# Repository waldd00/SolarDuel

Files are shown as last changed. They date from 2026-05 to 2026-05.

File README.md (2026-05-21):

# ☀️ SolarDuel

### *A dual-axis solar tracker built as a controlled experiment, not a demo.*

<p align="center">
  
  
  
  
  
  
  
</p>

> SolarDuel runs a **motor-driven tracker** and a **fixed reference panel** side-by-side under identical irradiance, then quantifies the energy difference with a calibrated INA226 power monitor. The goal isn't just to track the sun — it's to **prove the gain**, with numbers.

---

## 📋 Table of Contents

- [What Makes This Different](#-what-makes-this-different)
- [System Architecture](#-system-architecture)
- [Bill of Materials](#-bill-of-materials)
- [Hardware Schematic](#-hardware-schematic)
- [System Photo](#-system-photo)
- [Control Pipeline — The Engineering Core](#️-control-pipeline--the-engineering-core)
- [Signal Flow Diagram](#-signal-flow-diagram)
- [Logger & Dashboard](#-logger--dashboard)
- [Efficiency Analysis Results](#-efficiency-analysis-results)
- [Repository Structure](#-repository-structure)
- [How to Run](#-how-to-run)
- [3D Print Settings](#️-3d-print-settings)
- [License](#-license)

---

## 🎯 What Makes This Different

Most LDR trackers on the internet are a four-resistor bridge wired into an `analogWrite()` loop. SolarDuel treats the same problem as a **real control engineering exercise**:

| Concern | Naïve tracker | SolarDuel |
|---|---|---|
| Sensor noise | Raw `analogRead()` | Per-channel **Kalman filter** + ADC oversampling |
| Hunting at boundary | Single threshold → chatter | **Adaptive deadband** with **2.5× hysteresis exit** |
| Twitching on light flicker | Acts on every blip | **Debounced activation** (confirmation counter) |
| Derivative kick on setpoint | None / unfiltered | **Derivative-on-measurement** with bilinear LPF |
| Integrator runaway at servo limit | Windup → overshoot | **Trapezoidal integration** + **conditional anti-windup** |
| Mechanical snap | Step PWM commands | **Slew-rate limiter** (15 μs / loop) |
| Boot-time shock | Servo snaps to home | **1-second soft-start ramp** |
| Loop timing jitter | `delay()` in `loop()` | **Fixed 200 Hz scheduler**, tick-overflow safe |
| Data acquisition vs. control | Same MCU → coupling | **Two isolated MCUs** — STM32 controls, ESP32 observes |

The result is a servo that moves like it has inertia — smoothly, decisively, and without the cricket-leg twitching that plagues hobby trackers.

---

## 🏗️ System Architecture

SolarDuel is deliberately split into two electrically and logically isolated units. The tracker never knows it's being measured; the logger never affects motor timing.

```
┌──────────────────────────────────────────────────────────┐
│                    TRACKER UNIT  (STM32)                 │
│                                                          │
│   4× LDR ──ADC──► STM32-G031K8 ──PWM──► 2× Servo (Pan/Tilt)
│                       │                                  │
│                       └─ Kalman → PID → Slew → Soft-LPF  │
└──────────────────────────────────────────────────────────┘

┌──────────────────────────────────────────────────────────┐
│                    LOGGER UNIT  (ESP32)                  │
│                                                          │
│   Panel ──► 47 Ω load ──► INA226 ──I²C──► ESP-WROOM-32   │
│                                              │           │
│                                              ├─► WiFi → Browser dashboard
│                                              └─► /csv  → Timestamped CSV
└──────────────────────────────────────────────────────────┘
```

---

## 🧰 Bill of Materials

| Component | Role / Specification | Qty |
|---|---|---:|
| **STM32-NUCLEO-G031K8** | Tracker MCU — LDR sampling, control loop, PWM | 1 |
| **ESP-WROOM-32** | Logger MCU — INA226 readout, web server, CSV export | 1 |
| **LDR (GL5528 class)** | Cross-placed light sensors, 3.3 V dividers | 4 |
| **INA226** | 16-bit I²C power monitor, 0.1 Ω shunt | 1 |
| **Servo (MG996R / SG90)** | Pan + tilt actuators | 2 |
| **Solar panel** | 6 V / 150 mA monocrystalline | 2 |
| **Dummy load** | 47 Ω 5 W ceramic resistor (MPP-adjacent operating point) | 1 |
| **Resistors** | 10 kΩ LDR voltage dividers | 4 |
| **Power supply** | 5 V / 3 A external adapter (servos) | 1 |
| **Mechanical** | Custom 3D-printed pan-tilt frame, PLA | — |

---

## 🔌 Hardware Schematic

Full wiring for both units — tracker (STM32 + LDRs + servos) and logger (ESP32 + INA226 + dummy load):

📄 **[Hardware Schematic (PDF)](Hardware/hardware_schematic.pdf)**

**Wiring highlights:**
- INA226: `SDA → GPIO21`, `SCL → GPIO22` on the ESP32
- LDRs: 10 kΩ dividers to 3.3 V, outputs to STM32 ADC channels 0, 1, 4, 5
- Servos powered from the **external 5 V adapter** — never from the STM32 3.3 V rail
- 47 Ω dummy load sits across the panel terminals to pull operation toward the MPP

---

## 📷 System Photo

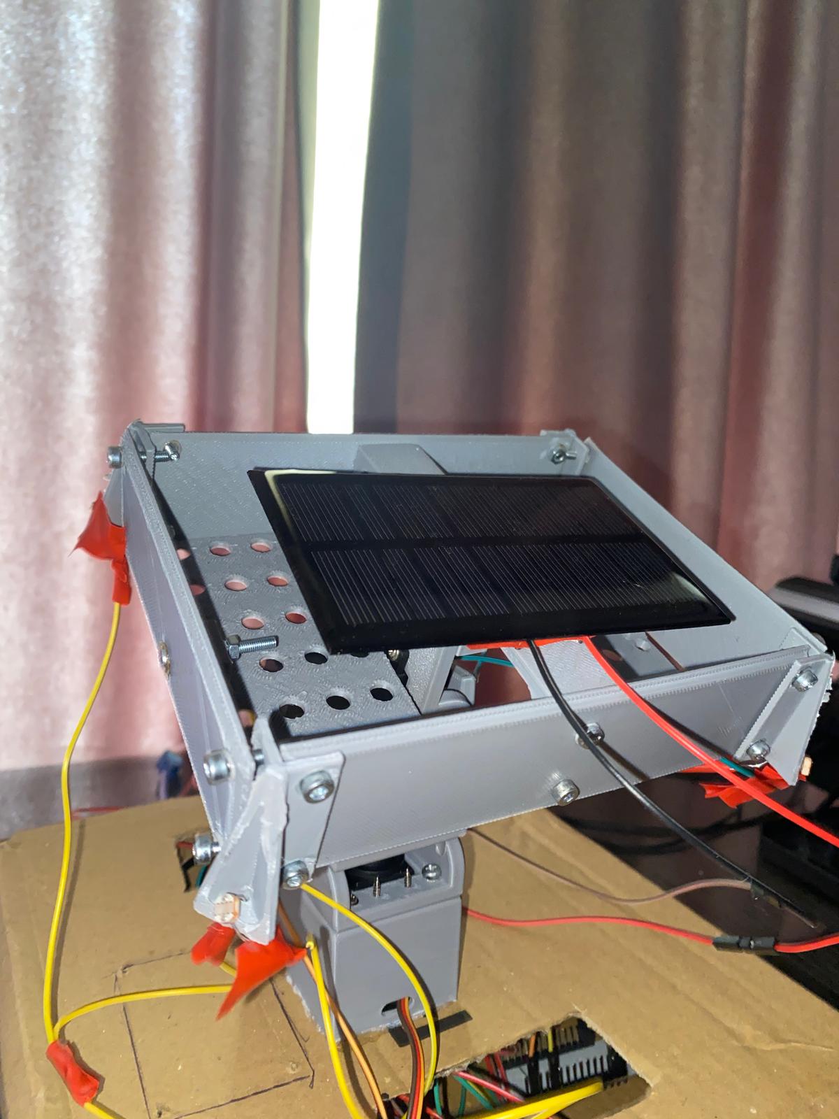
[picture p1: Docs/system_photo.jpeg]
System Photo


---

## ⚙️ Control Pipeline — The Engineering Core

The control stack is built as a chain of independent stages. Each stage solves one specific real-world failure mode of a basic LDR tracker.

### Stage 1 — ADC Oversampling
Each LDR is sampled **3 times in software** per loop and averaged. Cheap, immediate noise reduction before any filtering.

### Stage 2 — Per-Channel Kalman Filter
A 1-D Kalman filter runs on each of the four LDR streams independently:
```
k.p = k.p + q
kg  = k.p / (k.p + r)
k.x = k.x + kg · (z − k.x)
k.p = (1 − kg) · k.p
```
Tuned with `q = 2.0, r = 200.0` — biased toward smoothness because real solar light changes slowly relative to sensor noise.

### Stage 3 — Adaptive Deadband
A fixed deadband fails: too tight under bright sun (chatter), too loose at dawn (poor pointing). SolarDuel scales the deadband with **measured ambient light**:
```
tol = TOL_MIN + (ambient / 4096) × (TOL_MAX − TOL_MIN)   →   tol ∈ [50, 80] ADC units
```
Brighter ambient → larger differential noise → wider deadband. The controller stays still when it should.

### Stage 4 — Debounced Activation
A single noisy sample shouldn't wake the motor. The controller requires **`CONFIRM_THRESH = 2` consecutive out-of-band samples** before activating. Transient cloud edges no longer trigger pointless servo movements.

### Stage 5 — PID with Industrial-Grade Features

Not a textbook PID. Four upgrades over the naïve form:

**a) Trapezoidal (Tustin) integration**
```c
integral += 0.5 · (error + prev_error) · dt
```
More accurate than rectangular integration at the loop's ~200 Hz rate.

**b) Derivative on measurement**
Differentiating *error* causes a "derivative kick" on any setpoint change. SolarDuel differentiates the **measurement** instead — same dynamic response, no kick.

**c) Bilinear-LPF on derivative**
Raw `dD/dt` is a noise amplifier. The D-term passes through a first-order discrete LPF:
```
c1 = (1 − k) / (1 + k),   c2 = k / (1 + k),   k = α/2
d_filtered = c1 · d_filtered + c2 · (raw_d + prev_raw_d)
```
Removes the high-frequency chatter that makes textbook PID unusable on servos.

**d) Hysteresis exit + asymmetric thresholds**
Once active, the controller doesn't deactivate at the same threshold it entered:
```
thr_enter = tol         → wake the motor
thr_exit  = tol × 2.5   → only sleep when well back inside
```
This kills limit-cycling at the boundary — a problem most hobby trackers never solve.

### Stage 6 — Slew Rate Limiter
PID output is clamped to **±15 μs per loop** before being added to the servo target. Mechanically jarring fast moves are physically impossible.
```c
if (Δ >  MAX_DELTA_PER_LOOP) Δ =  MAX_DELTA_PER_LOOP;
if (Δ < -MAX_DELTA_PER_LOOP) Δ = -MAX_DELTA_PER_LOOP;
```

### Stage 7 — Conditional Anti-Windup at Saturation
When the target hits the mechanical limit (`PAN_MAX`, `TILT_MIN`, etc.), the integrator is checked: any component pushing **further into** the limit is zeroed, but useful "pull-back" integral is preserved. Cleaner than blanket clamping.

### Stage 8 — Float-Rounded PWM Write
A subtle but real artifact: casting `float → uint16_t` **truncates**, creating 1-step quantization jitter. All PWM writes use:
```c
__HAL_TIM_SET_COMPARE(&htim1, ch, (uint16_t)(pos + 0.5f));
```
The `+ 0.5f` converts truncation into proper rounding. Last source of micro-stepping eliminated.

### Stage 9 — Soft-Start
On boot, servos ramp from `PAN_MIN`/`TILT_MIN` to home over **50 steps × 20 ms = 1 second**, instead of snapping. Prevents power-up inrush and mechanical shock.

### Stage 10 — Fixed-Period, Overflow-Safe Scheduler
Loop runs at exactly **200 Hz** (`LOOP_PERIOD_MS = 5`) using non-blocking `HAL_GetTick()` comparison with **signed-cast tick-rollover handling** (49-day wrap is correctly handled). If execution falls more than 100 ms behind (e.g., debugger pause), the scheduler resyncs instead of catch-up-bursting.

---

## 📡 Signal Flow Diagram

```
4× LDR
   │
   ▼  ADC oversampling (3 samples / channel)
Kalman filter (per channel, q=2.0, r=200.0)
   │
   ▼  computed each loop
Edge averages  →  ambient light  →  adaptive deadband
   │
   ▼
Differential error    (right−left)   and   (bottom−top)
   │
   ▼
Debounce confirm counter   (CONFIRM_THRESH = 2)
   │
   ▼
PID — Tustin integration + filtered D-on-measurement
   │
   ▼  ±MAX_DELTA_PER_LOOP
Slew rate limiter
   │
   ▼
Target update  →  conditional anti-windup at limits
   │
   ▼  (+ 0.5f) cast
Float-rounded PWM compare register write
   │
   ▼
Servo
```

---

## 🌐 Logger & Dashboard

The ESP32 logger runs an independent **HTTP server + live JSON API** on the local network. No cloud, no app, no broker — open the IP in any browser.

**Features:**
- 🟢 1 Hz refresh of voltage, current, power, energy, efficiency
- 📈 Live **60-second rolling power graph** rendered on canvas
- ⏺ One-click **CSV recording** (`Time, V, mA, mW, Wh`) with timestamped filename
- 🔄 **Reset** clears energy accumulator and graph buffer
- 📊 Up to **3600 entries** (1-hour session at 1 Hz) buffered in RAM
- ⚡ Efficiency is computed against the panel's rated `PANEL_MAX_W = 0.9 W`

The dashboard is served as a single in-flash `PROGMEM` HTML page with vanilla JS — no external libraries, no build step.

---

## 📊 Efficiency Analysis Results

A 3-hour A/B session (10:00–13:00) under natural sunlight, panels swapped under matched irradiance, data processed in MATLAB.

| Metric | Tracker | Fixed Panel |
|---|---:|---:|
| Peak Efficiency | **74.44 %** | 35.00 % |
| Average Efficiency | **52.31 %** | 21.14 % |
| Peak Power | **670.0 mW** | 315.0 mW |
| Average Power | **470.8 mW** | 190.2 mW |
| Total Energy Harvested | **1.4125 Wh** | 0.5707 Wh |
| Tracker Energy Gain | — | **+147.5 %** |
| Avg. Instantaneous Gain | — | **180.3 %** |

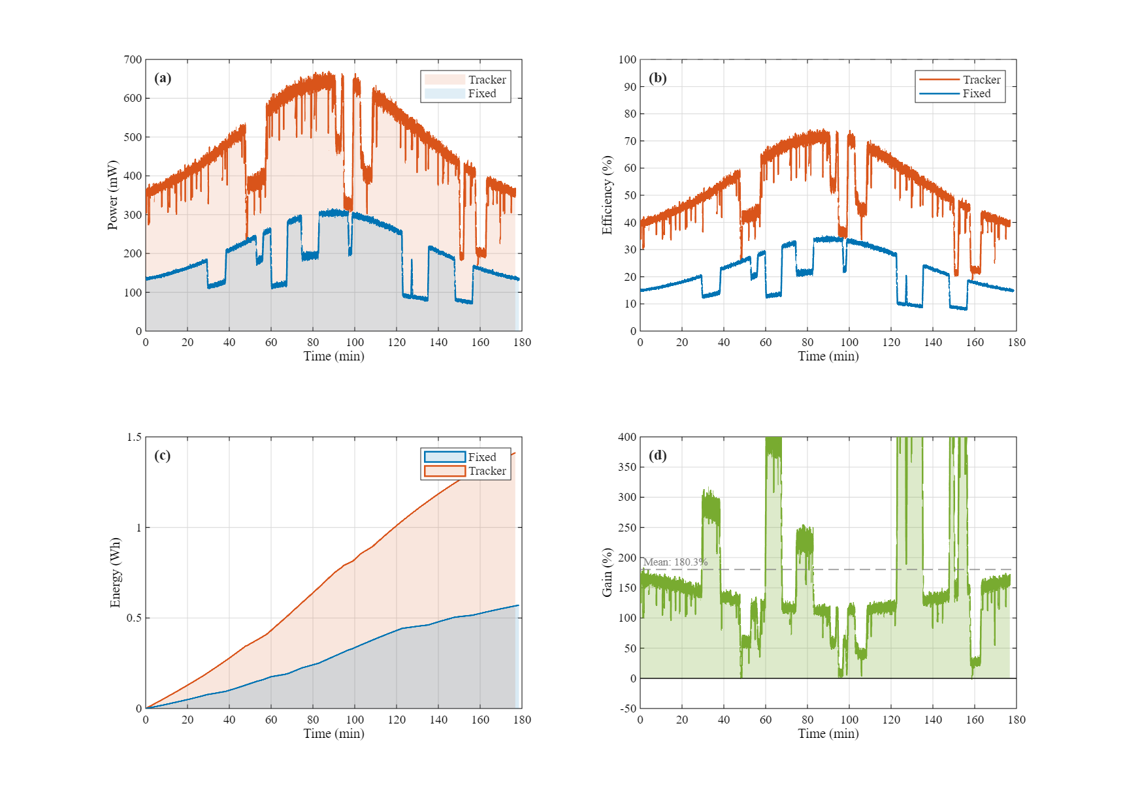
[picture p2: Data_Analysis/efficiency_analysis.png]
Efficiency Analysis


> **(a)** Instantaneous power output. The tracker consistently delivers more power, with both panels showing characteristic cloud-induced dips. **(b)** Panel efficiency relative to the 0.9 W rated maximum. **(c)** Cumulative energy harvested. **(d)** Instantaneous tracker gain over fixed — averaging **~180 %** highlights the value of continuous sun-facing orientation.

---

## 📂 Repository Structure

```
SolarDuel/
├── CAD_Files/STL/                  # Print-ready STL files for pan-tilt structure
├── Hardware/
│   └── hardware_schematic.pdf      # Full wiring schematic
├── Docs/
│   ├── dashboard.png               # Web dashboard preview
│   └── system_photo.jpeg           # Physical system photo
├── Software_STM32_Control/         # STM32CubeIDE project — tracker firmware (C, HAL)
├── Software_ESP32_Logger/          # Arduino IDE project — INA226 + web dashboard
└── Data_Analysis/
    ├── tracker_panel_data.csv      # Logged data — tracking panel
    ├── fixed_panel_data.csv        # Logged data — fixed panel
    ├── efficiency_analysis.m       # MATLAB analysis script
    └── efficiency_analysis.png     # Output figure
```

---

## 🧑‍💻 How to Run

**1 — Tracker (STM32)**
- Open `Software_STM32_Control` in STM32CubeIDE.
- Compile and flash to the NUCLEO-G031K8.
- Power LDRs from 3.3 V, servos from the external 5 V adapter.
- On boot, the soft-start routine ramps the servos to home over ~1 s.

**2 — Logger (ESP32)**
- Open `Software_ESP32_Logger` in Arduino IDE.
- Install the `INA226_WE` library from Library Manager.
- Set your WiFi credentials at the top of the sketch.
- Flash to the ESP32; wire `SDA → GPIO21`, `SCL → GPIO22`.
- Connect the active panel to the INA226 input, with the 47 Ω dummy load to ground.
- Open Serial Monitor (115200 baud) — the assigned IP is printed on boot.
- Browse to `http://<IP>` from any device on the same network.

**3 — Data Collection**
- Click **⏺ Start Recording** on the dashboard.
- Click **⏹ Stop & Download CSV** when done — file is saved with an ISO timestamp.
- Swap panels under matched conditions and repeat for the A/B pair.

**4 — Analysis**
- Place both CSVs and `efficiency_analysis.m` in the same folder.
- Run the script in MATLAB — summary table prints to console, figure saves as `efficiency_analysis.png`.

---

## 🖨️ 3D Print Settings

| Parameter | Value |
|---|---|
| Printer | Creality CR-10 Smart Pro |
| Slicer | Creality Slicer |
| Material | PLA |
| Infill | 15 % |
| Supports | Per-part — check STL orientation |

> **Attribution:** STL files in `CAD_Files/STL/` are sourced from [this Instructables project](https://www.instructables.com/SOLAR-TRACKER-TILTPAN-PANEL-FRAME-LDR-MOUNTS-RIG/) and are not original work. All credit goes to the original author. Files are shared here under the terms of the original license for non-commercial, educational use only.

---

## 📄 License

This project is licensed under the **MIT License** — see the [LICENSE](LICENSE) file for details.

---

<p align="center">
  <em>SolarDuel is an applied engineering study at the intersection of</em><br>
  <strong>automatic control theory · embedded systems · data-driven performance analysis.</strong>
</p>

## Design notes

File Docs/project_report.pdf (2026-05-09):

Contents

Contents

1 Abstract | 1
2 Introduction | 1
3 System Architecture | 2
4 Hardware and Circuit Design | 3
5 Sensors | 5
6 Actuators | 6
7 Control Strategy | 6
8 Software Architecture | 9
9 Data Collection and A/B Test Method | 9
10 Efficiency Analysis | 10
11 Conclusions | 13
Bibliography | 14
A STM32 Control Loop — Core Flow | 14

i

Chapter 2. Introduction

### 1. Abstract

This study presents the design and implementation of a dual-axis solar tracking system that determines the solar azimuth and elevation angle using differential signals from four LDR sensors. The system consists of two independent units: an STM32G031K8 microcontroller for motor control and an ESP32 microcontroller for power measurement and data logging. Power monitoring is performed via an INA226 module over the I2C protocol.

The control architecture employs a multi-layer signal processing pipeline consisting of a Kalman filter, moving average, a full PID controller with anti-windup and derivative filter, hysteresis dead band, and exponential position smoothing. Power data acquired across a 47 Ω dummy load is monitored in real time through a live web dashboard running on the ESP32 and recorded in CSV format.

Comparative A/B testing between the tracking and fixed panel configurations shows that the tracker produces %147.5 more gross energy over a three-hour measurement session. A parasitic consumption analysis reveals that the MG996R servo motors present a disproportionate load relative to the panel capacity, highlighting the critical role of actuator selection in small-scale tracking systems.

### 2. Introduction

Panel efficiency in solar energy systems is directly related to the angular orientation of the panel relative to incident irradiance. A fixed-mount photovoltaic panel can only achieve its optimum angle for a limited period each day due to the apparent motion of the sun. Solar tracking systems aim to minimise this loss by continuously orienting the panel perpendicular to the incoming radiation [1].

While single-axis trackers follow only the azimuth angle, dual-axis systems control both azimuth and elevation simultaneously to achieve higher energy yield [2]. This work presents a system in which a solar panel mounted on a two-servo pan-tilt mechanism is directed by differential signals derived from four LDR sensors.

The primary objectives of the project are:

- Sun angle estimation using four cross-placed LDR sensors
- Jitter-free, precise servo control through a multi-layer control architecture
- High-accuracy power and energy measurement with the INA226
- A live ESP32-based web dashboard with browser-side CSV recording
- Quantitative efficiency comparison against a fixed panel

Chapter 3. System Architecture

### 3. System Architecture

The system is intentionally split into two isolated units to ensure that data acquisition is never affected by motor control timing or interrupt latency.

Tracker Unit (STM32): Processes LDR signals and drives the servo motors via PWM. All control algorithms run on this unit.

Logger Unit (ESP32): Reads panel power data from the INA226, serves a live web dashboard, and handles CSV recording. It has no direct connection to the motor control unit.


Figure 3.1: Assembled dual-axis solar tracking system

Chapter 4. Hardware and Circuit Design

### 4. Hardware and Circuit Design

### 4.1 Bill of Materials

Table 4.1: Project bill of materials

Component | Role / Specification | Qty
STM32-NUCLEO-G031K8 Primary MCU — motor and LDR control | 1
ESP-WROOM-32 | Secondary MCU — logging and web server | 1
LDR | Light sensor, 10 kΩ voltage divider | 4
INA226 | Bi-directional power monitor (I2C, 0.1 Ω shunt) 1
Dummy Load | 47 Ω 5W ceramic resistor | 1
Servo Motor | Pan and tilt axis actuators | 2
Solar Panel | 6 V 150 mA monocrystalline | 2
Resistor | 10 kΩ LDR voltage dividers | 4
Power Supply | 5 V 3 A external adapter | 1
Mechanical | Custom 3D-printed PLA pan-tilt structure [3] | —

### 4.2 Circuit Design

A critical design decision is powering the servo motors from an external 5 V adapter rather than the STM32’s 3.3 V rail. The inrush current drawn by the servos would otherwise cause voltage drops on the MCU power rail, corrupting ADC readings. The 47 Ω dummy load was selected to force the 6 V/150 mA panel to operate near its maximum power point.

Chapter 4. Hardware and Circuit Design

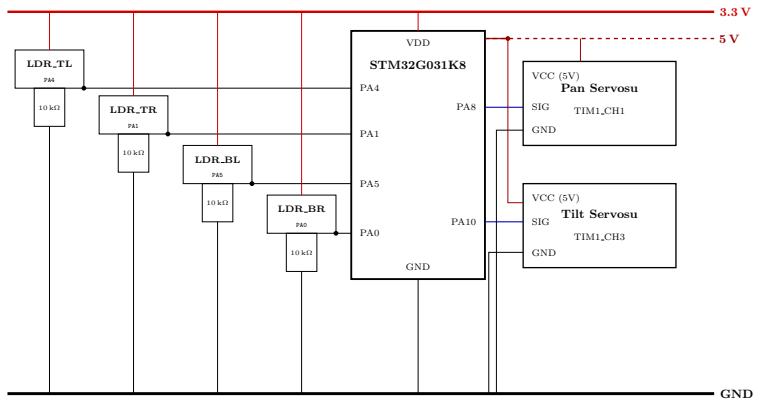
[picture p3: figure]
GND; LDR TL; LDR TR; LDR BL; LDR BR; STM32G031K8; VDD; Pan Servosu; TIM1 CH1; VCC (5V); SIG; Tilt Servosu; TIM1 CH3

Figure 4.1: System circuit schematic (1/2)

### 3.3 V

GND

G¨une¸s

Paneli

6V / 150mA

Monokristal

+

−

INA226

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
### 47 Ω

5W

ESP32-WROOM-32

GPIO21 (SDA)

GPIO22 (SCL)

3.3V

GND

3V3

GND

SDA

SCL

Figure 4.2: System circuit schematic (2/2)

Chapter 5. Sensors

### 5. Sensors

### 5.1 LDR (Light-Dependent Resistor)

An LDR is a photoconductive element whose resistance decreases proportionally with incident light intensity — from several MΩ in darkness to a few hundred Ω under full illumination.

Four LDRs are placed at the corners of the panel frame in a cross configuration: top-left, top-right, bottom-left, and bottom-right. Each sensor forms a voltage divider with a 10 kΩ fixed resistor, with the output fed to an STM32 ADC input. The differential signal method is defined as:

epan = ADClef t − ADCright | (5.1)
etilt = ADCtop − ADCbottom | (5.2)

When epan > 0 the panel rotates left; when etilt > 0 it tilts upward. Both errors approaching zero indicates the panel is perpendicular to the sun.

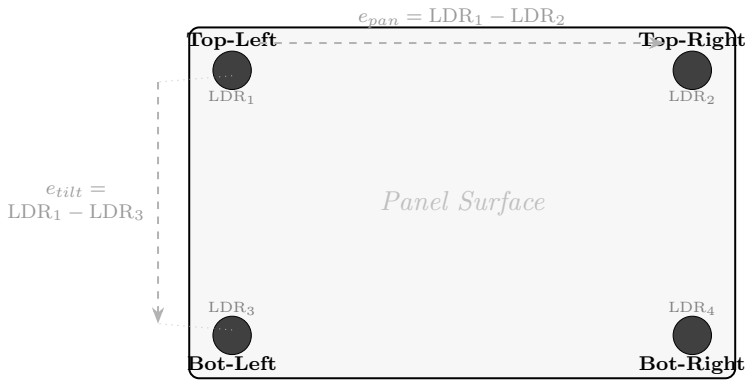
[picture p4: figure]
Panel Surface; Top-Left; LDR1; Top-Right; LDR2; Bot-Left; LDR3; Bot-Right; LDR4; epan = LDR1 − LDR2; etilt = LDR1 − LDR3

Figure 5.1: Cross-placement of LDR sensors at panel corners with differential signal definitions

### 5.2 INA226 Power Monitor

The INA226 is an I2C power monitor that measures the voltage drop across a shunt resistor to compute current, bus voltage, and power with high accuracy [4]. A 0.1 Ω shunt resistor is used with a maximum measurement range of 1.5 A.

Listing 5.1: INA226 initialisation and calibration

1 | ina226 . setResistorRange (0.1 , 1.5) ; | // 0.1 Ohm shunt , max 1.5
| A
2 | ina226 . setAverage ( INA226_AVERAGE_16 ) ; | // 16 - sample hardware
| averaging

Chapter 7. Control Strategy

Hardware averaging over 16 samples suppresses high-frequency noise at the sensor level. Cumulative energy is computed via discrete integration:

EW h =

## XPW ·

∆t
3600

(5.3)

### 6. Actuators

### 6.1 Servo Motors

Servo motors are angle-positioning actuators controlled by the duty cycle of a PWM signal. Typically, a 1 ms pulse corresponds to 0° and a 2 ms pulse to 180°.

Two servo motors are used — one for the pan (azimuth) axis and one for the tilt (elevation) axis — driven by STM32 Timer1 PWM outputs independently. Since the position value is stored as a float, a rounding correction is applied at the PWM write step to prevent quantisation jitter:

Listing 6.1: Float-preserving PWM write

1 | __HAL_TIM_SET_COMPARE (& htim1 , TIM_CHANNEL_1 ,
2 | ( uint16_t ) ( pos_pan + 0.5 f ) ) ;

The +0.5f offset converts truncation to proper rounding, eliminating the last source of micro-stepping artifacts. A soft-start routine ramps the servos to the home position over 1 second on power-up.

### 7. Control Strategy

The system employs a six-layer signal processing pipeline in which each layer addresses a specific real-world problem. The full pipeline is illustrated in Figure 7.1 and all tunable parameters are summarised in Table 7.1.

Chapter 7. Control Strategy

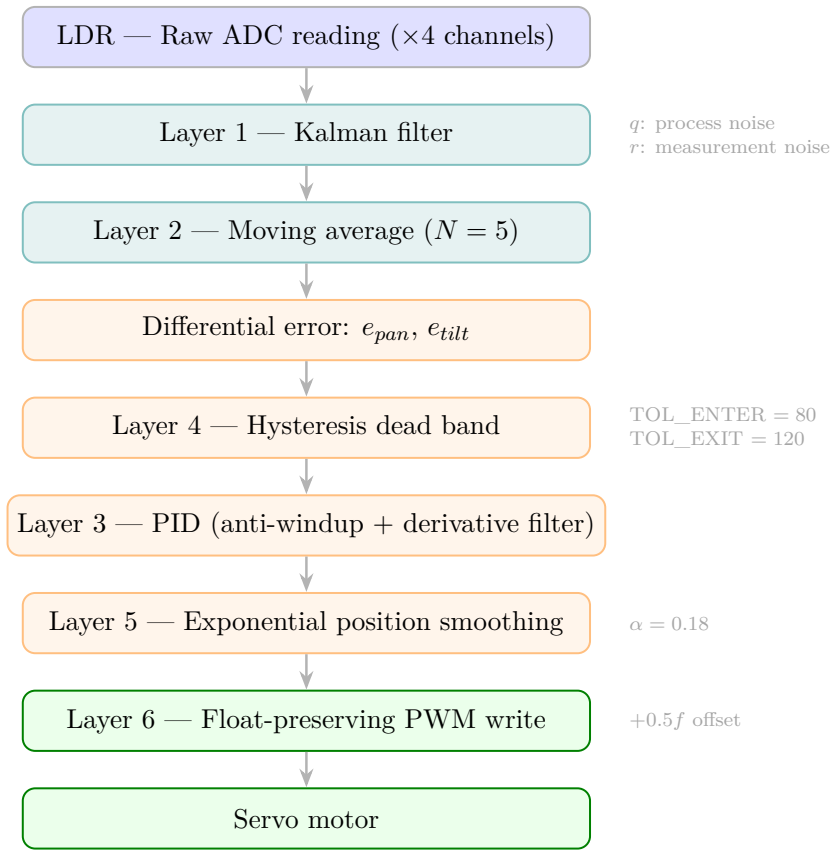
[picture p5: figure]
LDR — Raw ADC reading (×4 channels); Layer 1 — Kalman filter; Layer 2 — Moving average (N = 5); Differential error: epan, etilt; Layer 4 — Hysteresis dead band; Layer 6 — Float-preserving PWM write; Servo motor; q: process noise r: measurement noise; TOL_ENTER = 80 TOL_EXIT = 120; +0.5f offset

Layer 3 — PID (anti-windup + derivative filter)

Layer 5 — Exponential position smoothing

Sensor | Filtering | Control | Output

Figure 7.1: Control system signal processing pipeline

Table 7.1: Control and system parameter summary

Layer / Component | Parameter | Value
Kalman filter | Process noise q | Tunable
| Measurement noise r | Tunable
Moving average | Window size N | 5
Hysteresis dead band | Activation threshold TOL_ENTER | 80
| Deactivation threshold TOL_EXIT | 120
Exponential smoothing Smoothing factor α | 0.18
PWM write | Rounding offset | +0.5f
INA226 | Shunt resistance | 0.1 Ω
| Maximum current | 1.5 A
| Hardware averaging | 16 samples
Solar panel | Rated voltage | 6 V
| Rated current | 150 mA
| Maximum power | 0.9W
Dummy load | Resistance | 47 Ω
Servo (MG996R) | Idle consumption (×2) | 1700 mW
| Active duty cycle | 2.5%

Chapter 7. Control Strategy

### 7.1 Layer 1 — Kalman Filter

Raw ADC readings contain significant high-frequency noise, particularly under partially cloudy conditions. A 1D Kalman filter runs independently on each of the four LDR channels, separating genuine light-level changes from sensor noise [5].

xˆk|k = ˆxk|k−1 + Kk(zk − xˆk|k−1) | (7.1)

Increasing the measurement noise parameter r produces a smoother but slower response.

### 7.2 Layer 2 — Moving Average (N = 5)

A 5-sample circular moving average is applied on top of the Kalman output. This dual-stage filtering virtually eliminates transient spikes caused by cloud edges or mechanical vibration.

### 7.3 Layer 3 — PID Controller

The differential error feeds into a full PID controller with two key enhancements:

Anti-windup (integral clamping): When the servo is at its mechanical limit, the integrator is hard-clamped to ±ilimit to prevent windup and overshoot on release.

Filtered derivative: A first-order low-pass filter is applied to the raw derivative term before it reaches the output:

df iltered = α · draw + (1 − α) · df iltered,prev | (7.2)

### 7.4 Layer 4 — Hysteresis Dead Band

A two-threshold hysteresis band prevents the chattering that occurs when using a single threshold:

- TOL_ENTER = 80: Motor activates when error exceeds this value
- TOL_EXIT = 120: Motor deactivates only when error drops below this value

### 7.5 Layer 5 — Exponential Position Smoothing

The target servo position is passed through a first-order exponential smoother to produce an organic, inertia-like motion profile:

pos = pos + α · (target − pos), | α = 0.18 | (7.3)

### 7.6 Layer 6 — Float-Preserving PWM Write

Direct float → uint16_t casting truncates rather than rounds, creating invisible one-step quantisation jitter. The +0.5f offset corrects this.

Chapter 9. Data Collection and A/B Test Method

### 8. Software Architecture

### 8.1 STM32 Firmware

The STM32 firmware is written in C using the HAL library. The main loop executes ADC reading, Kalman + moving average filtering, PID computation, and PWM write in sequence.

### 8.2 ESP32 Web Server

The ESP32 exposes the following HTTP endpoints via the AsyncWebServer library:

Table 8.1: ESP32 HTTP endpoints

Endpoint Function

/ | Live web dashboard (HTML)
/data | Real-time measurement data (JSON)
/start | Begin CSV recording session
/stop | Stop recording and prepare download
/csv | Download recorded data as CSV
/reset | Clear all runtime data

The last 3600 measurements (1 hour) are held in a circular buffer in RAM and served via chunked transfer, avoiding large heap allocations.

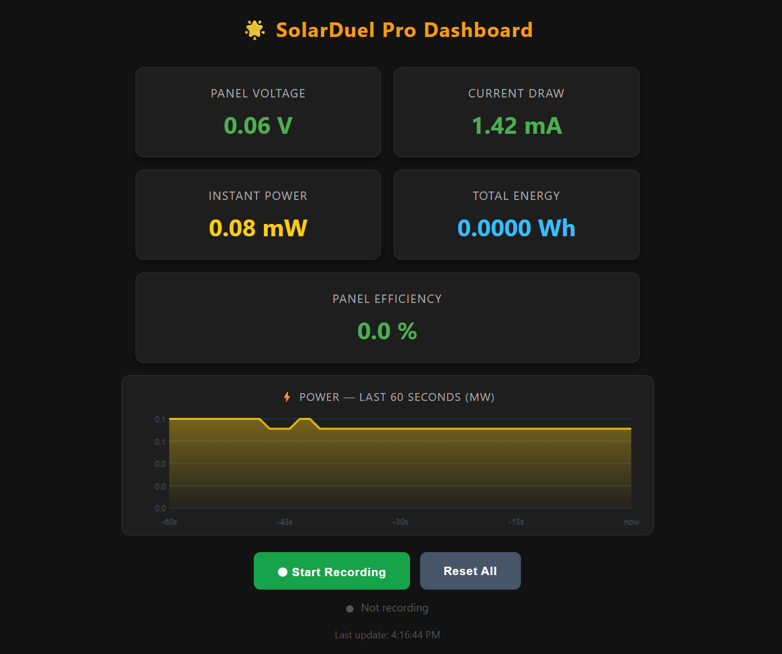
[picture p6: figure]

Figure 8.1: ESP32 live web dashboard

### 9. Data Collection and A/B Test Method

Since both panels cannot be connected to the INA226 simultaneously, an A/B test methodology was used. Under matched irradiance conditions, the tracker panel and the

Chapter 10. Efficiency Analysis

fixed panel were each connected to the same dummy load in separate sessions. Recording was initiated via the Start Recording button on the dashboard and the resulting CSV was downloaded with Stop & Download CSV.

Each dataset contains time (s), voltage (V), current (mA), power (mW), and cumulative energy (Wh). The dataset used for analysis consists of 10 800 rows (3-hour session, 1 sample per second).

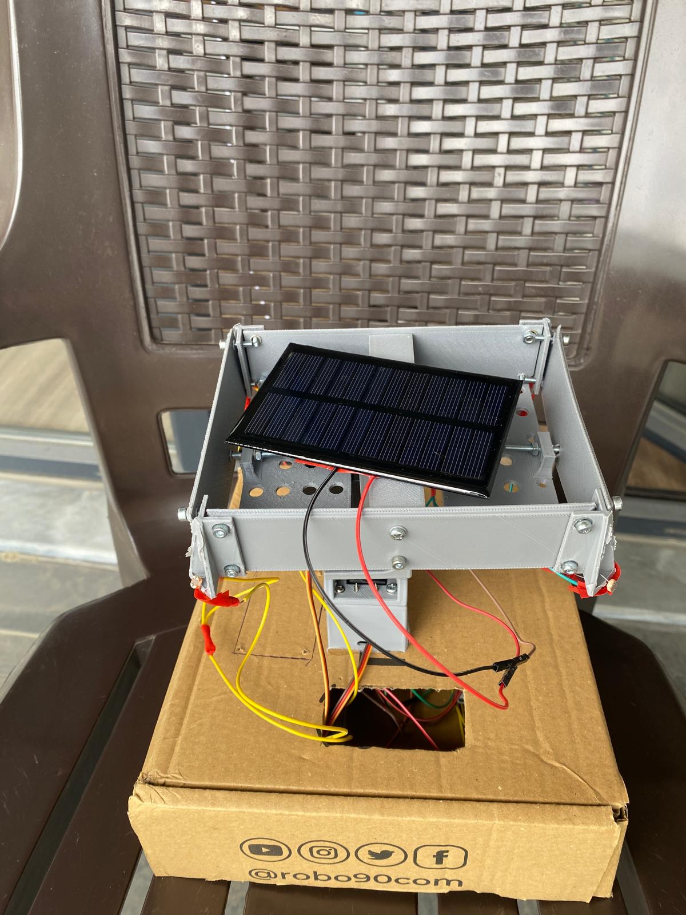
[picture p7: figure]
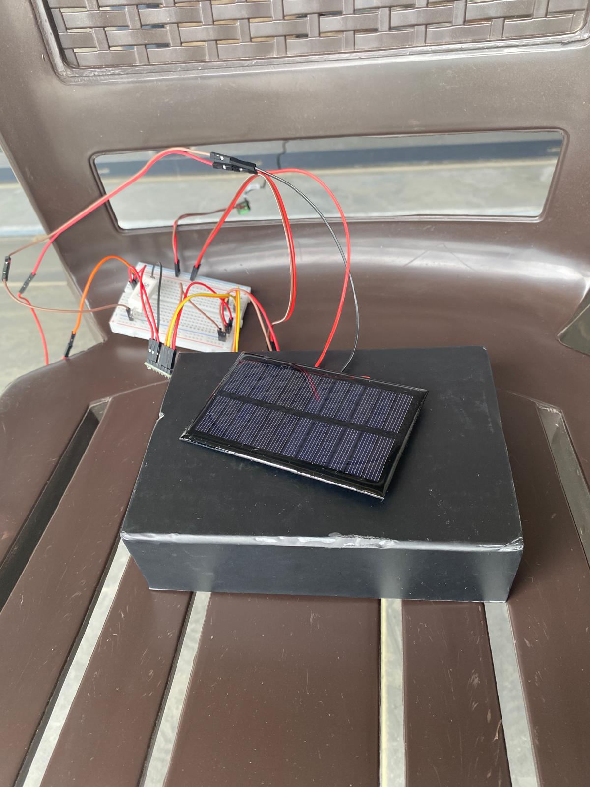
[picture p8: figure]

(a) Tracker panel session | (b) Fixed panel session

Figure 9.1: A/B test setup: each panel connected separately to the same load for matched measurements

### 10. Efficiency Analysis

The MATLAB analysis script (efficiency_analysis.m) processes both CSV files and produces a four-panel comparative figure.

Chapter 10. Efficiency Analysis

### 10.1 Results Summary

Table 10.1: Tracker vs fixed panel comparative efficiency results

Metric | Tracker Fixed Panel
Peak Efficiency | 74.44% | 35.00%
Average Efficiency | 52.31% | 21.14%
Peak Power | 670.0 mW | 315.0 mW
Average Power | 470.8 mW | 190.2 mW
Total Energy Harvested | 1.4125Wh | 0.5707Wh
Energy Gain | +147.5% | —
Avg. Instantaneous Gain | 180.3% | —

### 10.2 Analysis Figures

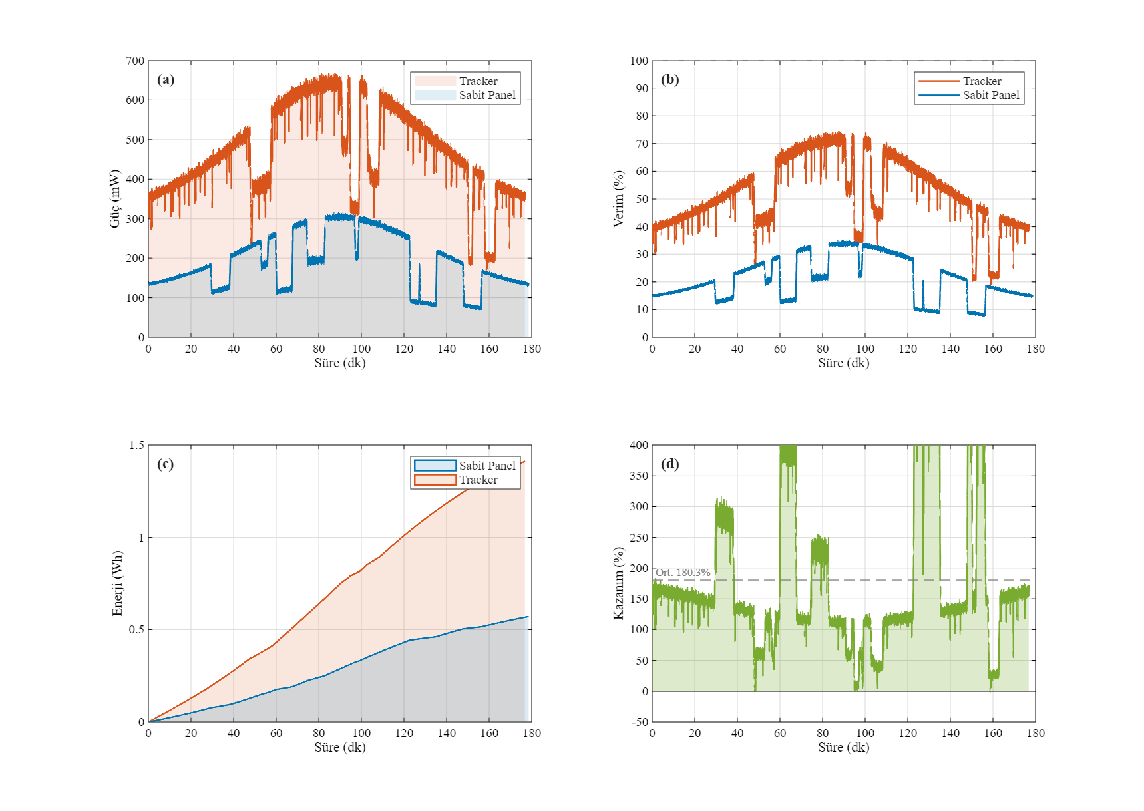
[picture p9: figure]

Figure 10.1: Comparative efficiency analysis: (a) instantaneous power, (b) panel efficiency,
(c) cumulative energy, (d) tracker gain over fixed

Figure 10.1(a) shows that the tracker consistently delivers higher power throughout the session, with characteristic cloud-induced dips visible in both curves. Figure 10.1(c) shows the tracker harvesting 1.41Wh versus 0.57Wh for the fixed panel over the same period. The average instantaneous gain of 180.3% shown in Figure 10.1(d) confirms the advantage of continuous sun-facing orientation.

Chapter 10. Efficiency Analysis

### 10.3 Net Energy Gain and Parasitic Consumption Analysis

For the gross energy advantage to be meaningful from an engineering standpoint, the parasitic energy consumed by the tracking system itself must be accounted for. This analysis is critical for evaluating the true efficiency of solar tracking systems, as emphasised by Seme et al. [2].

### 10.3.1 Parasitic Consumption Estimate

Table 10.2: Tracker unit component power consumption

Component | Idle (mW) Active (mW) | Source
STM32G031K8 | 15 | 15 | Datasheet
Servo Motor ×2 (MG996R) | 1700 | 5000 MG996R Datasheet
Total | 1715 | 5015

The servos are not continuously active; they engage only when the LDR differential error exceeds the hysteresis threshold (TOL_ENTER = 80). Given that the sun moves approximately 15° per hour, the servo active duty cycle is estimated at approximately 2.5% (roughly 3 seconds of motion every 2 minutes).

### 10.3.2 Net Energy Calculation

Parasitic energy over the 3-hour session:

ESTM32 = 15 mW × 3 h = 45 mWh | (10.1)
Eservo,idle = 1700 mW × (1 − 0.025) × 3 h = 4972 mWh | (10.2)
Eservo,active = 5000 mW × 0.025 × 3 h = 375 mWh | (10.3)
Eparasitic = 45 + 4972 + 375 = 5392 mWh ≈ 5.392Wh | (10.4)

Table 10.3: Net energy gain analysis (3-hour session)

Parameter | Value (Wh) | Note
Tracker gross energy | 1.4125 | INA226 measurement
Fixed panel energy | 0.5707 | INA226 measurement
Gross energy gain | +0.8418 | Tracker − Fixed
Parasitic consumption | −5.3920 STM32 + 2× MG996R
Net energy gain | −4.550 | Gross − Parasitic

The net energy analysis reveals that the MG996R servos present a disproportionate parasitic load for a 6 V/150 mA panel: each servo draws approximately 850 mW at idle, close to the panel’s entire rated output of 900 mW. This finding underscores the critical

Chapter 11. Conclusions

importance of actuator selection in small-scale tracking systems. A redesign using lower-power micro-servos (e.g., SG90: ∼50 mW/servo idle) or higher-capacity panels is expected to yield a positive net energy gain.

### 11. Conclusions

The dual-axis solar tracking system presented in this work produces 147.5% more gross energy than the fixed panel configuration over a three-hour measurement session. The net energy analysis shows that the MG996R servo motors consume more power at idle than the panel produces, highlighting that actuator selection is the dominant factor in the energy balance of small-scale tracking systems.

The multi-layer control architecture effectively suppresses high-frequency LDR noise and servo chattering. The physical separation of the STM32 tracker unit and the ESP32 logger unit ensures that data acquisition is not affected by motor control latency.

Strengths of the system include the real-time web dashboard, browser-side CSV recording, and hardware-level measurement averaging (INA226 16-sample average). Limitations include the sequential A/B test methodology, which cannot capture both panels simultaneously, and the 3-hour measurement window.

Appendix A. STM32 Control Loop — Core Flow

Bibliography

[1] H. Mousazadeh, A. Keyhani, A. Javadi, H. Mobli, K. Abrinia, and A. Sharifi, “A review of principle and sun-tracking methods for maximizing solar systems output,” Renewable and Sustainable Energy Reviews, vol. 13, no. 8, pp. 1800–1818, 2009.
[2] S. Seme, G. Stumberger, and J. Vorsic, “Maximum efficiency trajectories of a two-axis sun tracking system determined considering tracking system consumption,” IEEE Transactions on Power Electronics, vol. 26, no. 4, pp. 1280–1290, 2011.
[3] Instructables, “Solar tracker tilt/pan panel frame ldr mounts rig,” 2020.
[4] Texas Instruments, INA226 Bi-Directional Current/Power Monitor Datasheet, 2015.
[5] R. E. Kalman, “A new approach to linear filtering and prediction problems,” Journal of Basic Engineering, vol. 82, no. 1, pp. 35–45, 1960.
A. STM32 Control Loop — Core Flow

Listing A.1: STM32 main control loop (simplified)

1 | while (1) {
2 | // 1. Read ADC
3 | adc_top | = HAL_ADC_Read ( CH1 ) ;
4 | adc_bot | = HAL_ADC_Read ( CH2 ) ;
5 | adc_left | = HAL_ADC_Read ( CH3 ) ;
6 | adc_right = HAL_ADC_Read ( CH4 ) ;

7
8 | // 2. Kalman + moving average
9 | kalman_update (& kf_top , adc_top ) ;
10 | ma_top = moving_avg ( kf_top . x ) ;
11 | // ...

12
13 | // 3. Differential error
14 | e_pan | = ma_left - ma_right ;
15 | e_tilt = ma_top | - ma_bot ;

16
17 | // 4. Hysteresis + PID + exponential smoothing + PWM write
18 | if ( fabs ( e_pan ) > TOL_ENTER ) {
19 | pid_out_pan = pid_compute (& pid_pan , e_pan ) ;
20 | pos_pan = pos_pan + 0.18 f * ( pid_out_pan - pos_pan ) ;
21 | __HAL_TIM_SET_COMPARE (& htim1 , TIM_CHANNEL_1 ,
22 | ( uint16_t ) ( pos_pan + 0.5 f ) ) ;
23 | }
24 | HAL_Delay (20) ;
25 | }

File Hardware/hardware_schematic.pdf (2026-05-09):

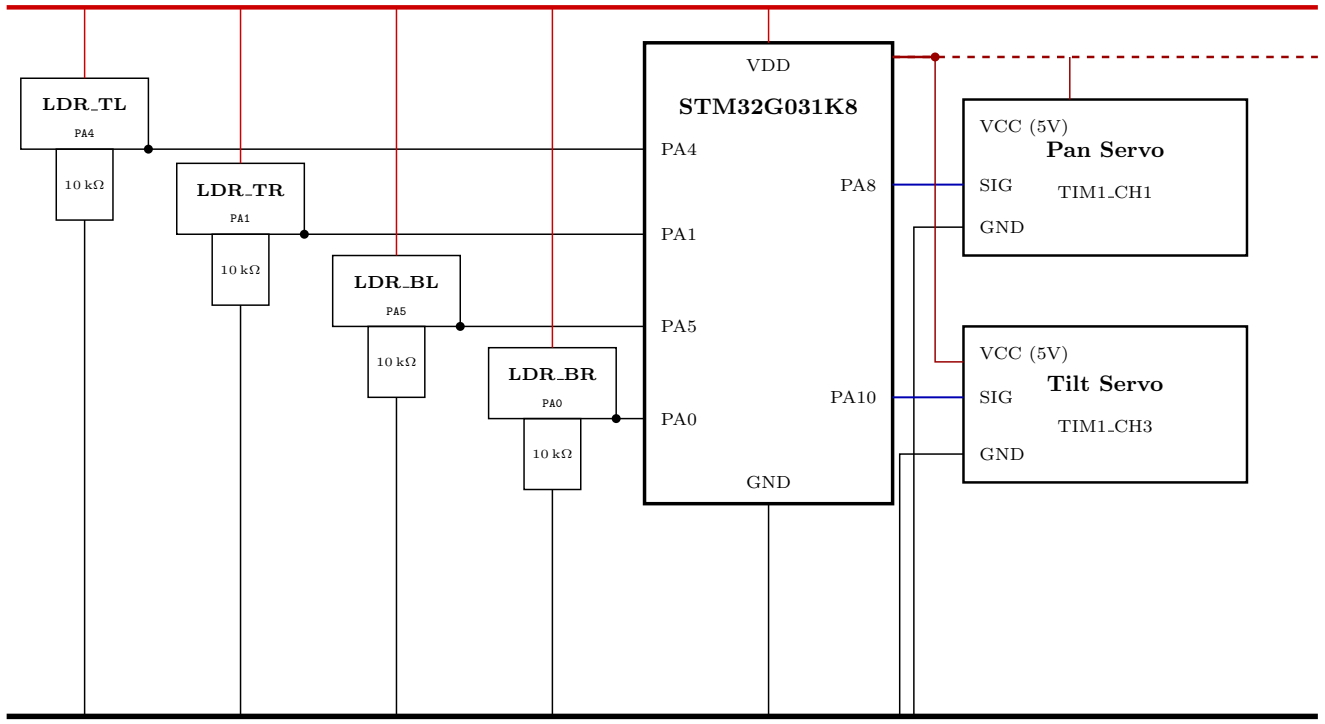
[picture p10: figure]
LDR TL; LDR TR; LDR BL; LDR BR; STM32G031K8; VDD; GND; Pan Servo; TIM1 CH1; VCC (5V); SIG; Tilt Servo; TIM1 CH3

## 3.3 V

## 5 V

## GND

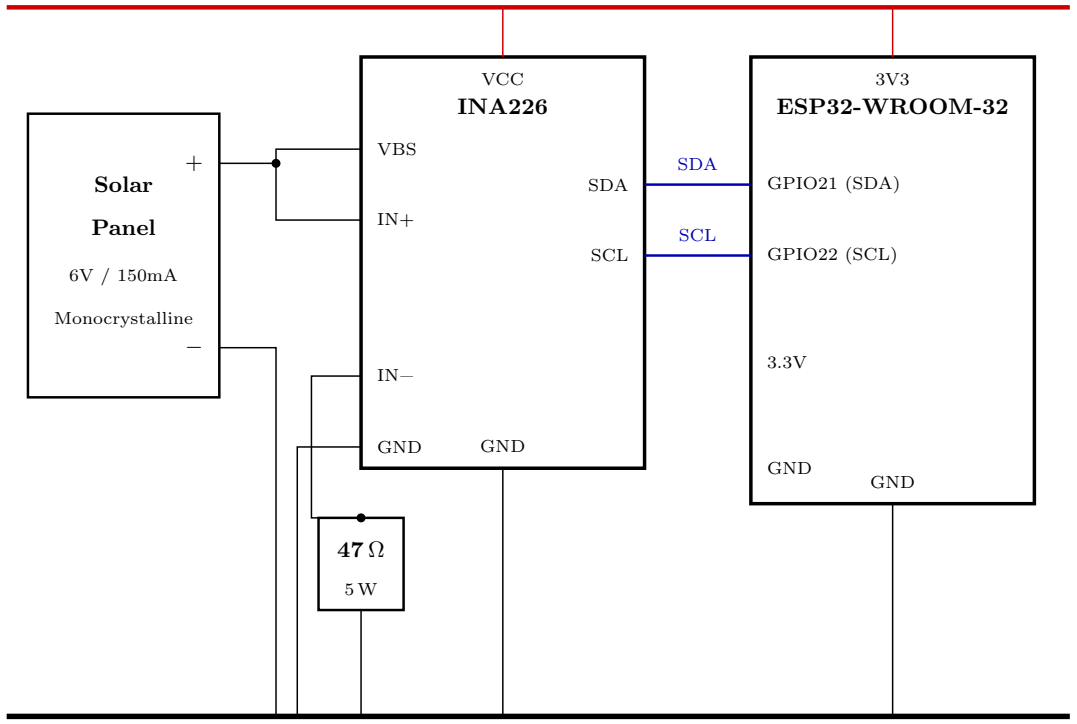
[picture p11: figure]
Solar; Panel; Monocrystalline; INA226; VBS; GND; SDA; SCL; VCC; ESP32-WROOM-32; GPIO21 (SDA); GPIO22 (SCL)

## 3.3 V

## GND

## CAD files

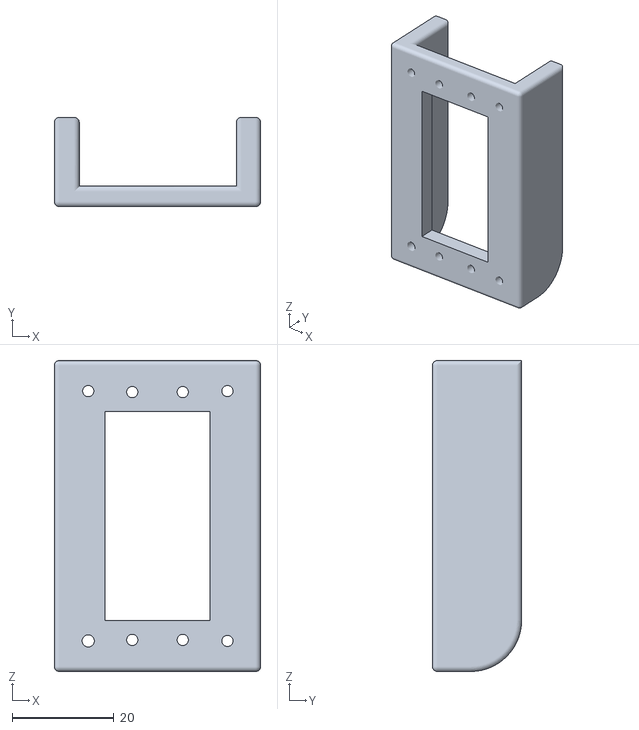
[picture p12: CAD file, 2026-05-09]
CAD_Files/STL/MG995_TILT_PAN_base_lid.STL
40.5 x 17.5 x 61.0

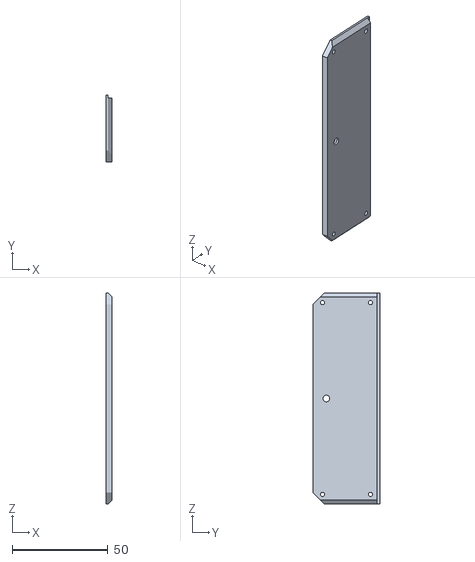
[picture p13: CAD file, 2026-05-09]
CAD_Files/STL/SOLAR_PANEL_side_110mm.STL
3.00 x 35.0 x 110.0

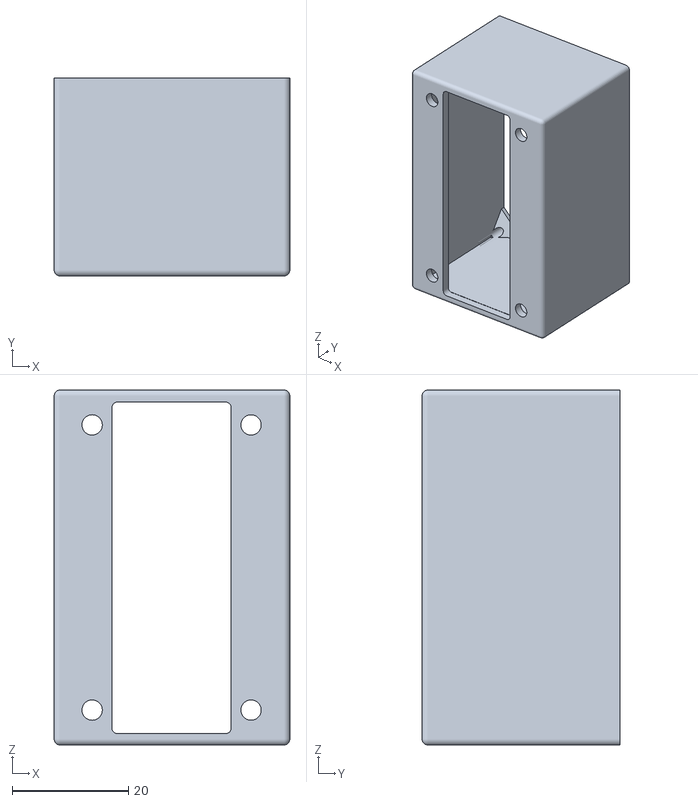
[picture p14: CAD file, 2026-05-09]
CAD_Files/STL/MG995_TILT_PAN_base_block.STL
40.5 x 34.0 x 61.0

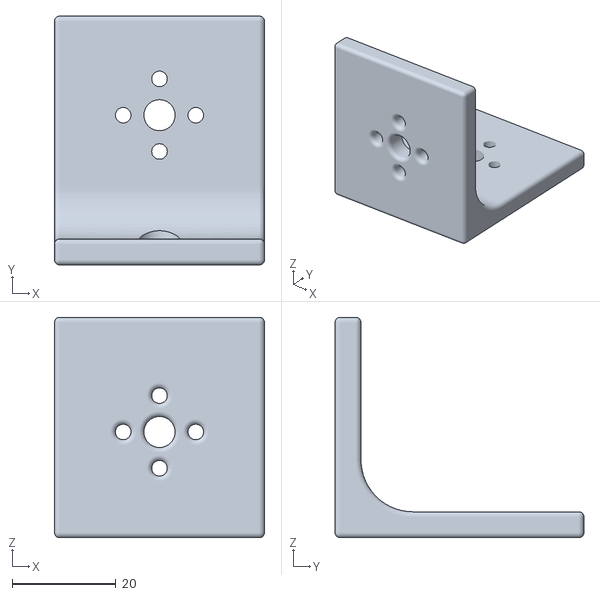
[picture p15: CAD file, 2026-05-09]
CAD_Files/STL/MG995_TILT_PAN_corner.STL
40.5 x 48.0 x 42.5

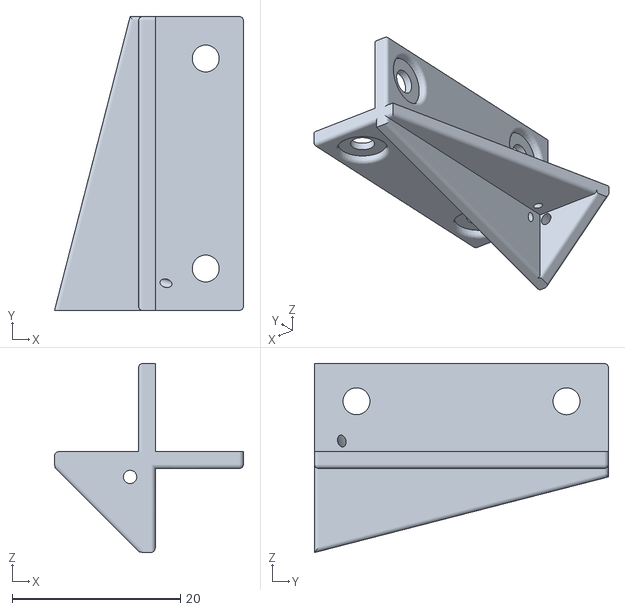
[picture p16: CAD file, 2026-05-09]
CAD_Files/STL/SOLAR_PANEL_corner.STL
22.5 x 35.0 x 22.5

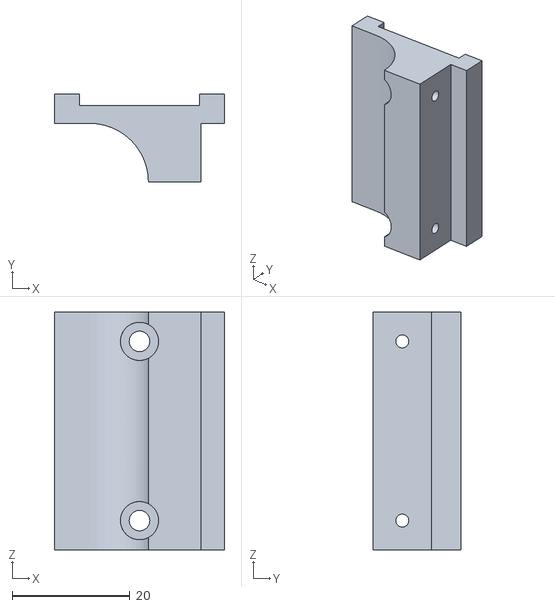
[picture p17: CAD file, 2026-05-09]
CAD_Files/STL/MG995_TILT_PAN_vert_bracket.STL
29.0 x 15.0 x 40.5

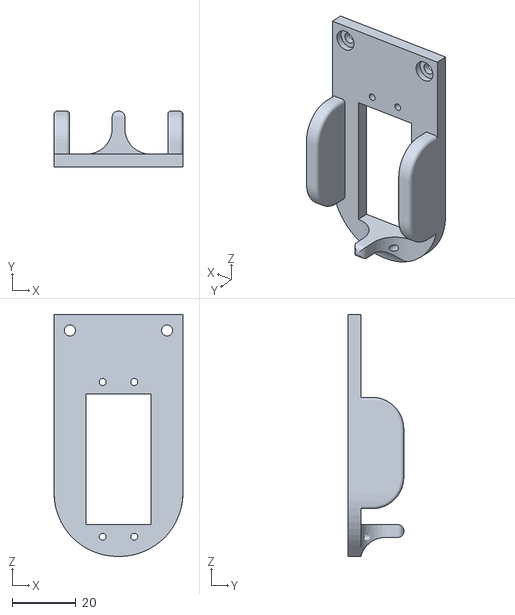
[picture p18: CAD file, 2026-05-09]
CAD_Files/STL/MG995_TILT_PAN_vert_arm.STL
40.5 x 17.5 x 76.0

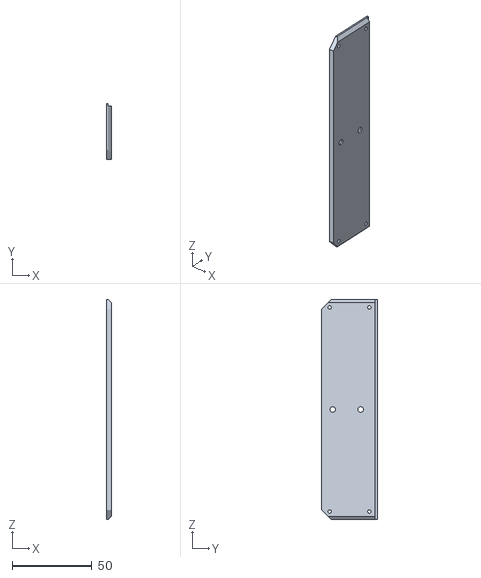
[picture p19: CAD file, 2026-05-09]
CAD_Files/STL/SOLAR_PANEL_side_138mm.STL
3.00 x 35.0 x 138.0

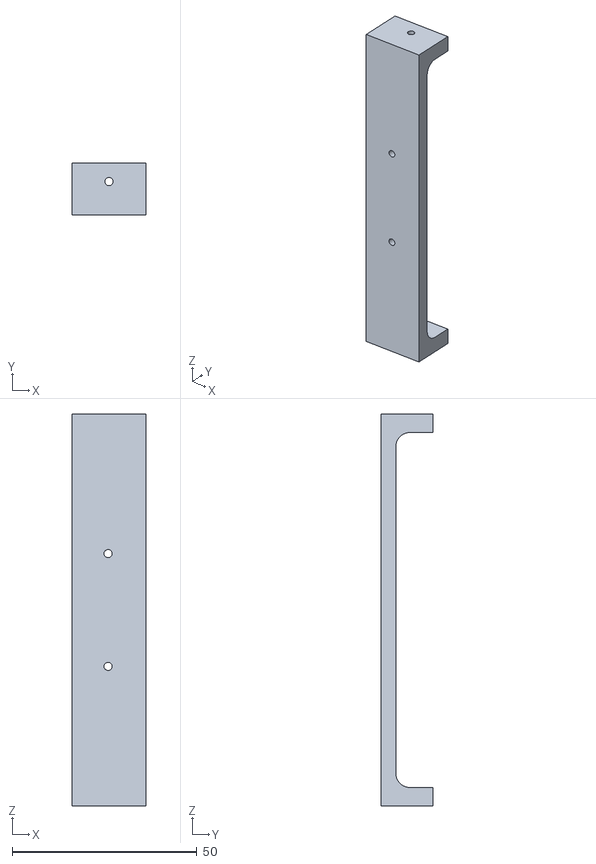
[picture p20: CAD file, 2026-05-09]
CAD_Files/STL/SOLAR_PANEL_stay_110mm.STL
20.0 x 14.0 x 106.0

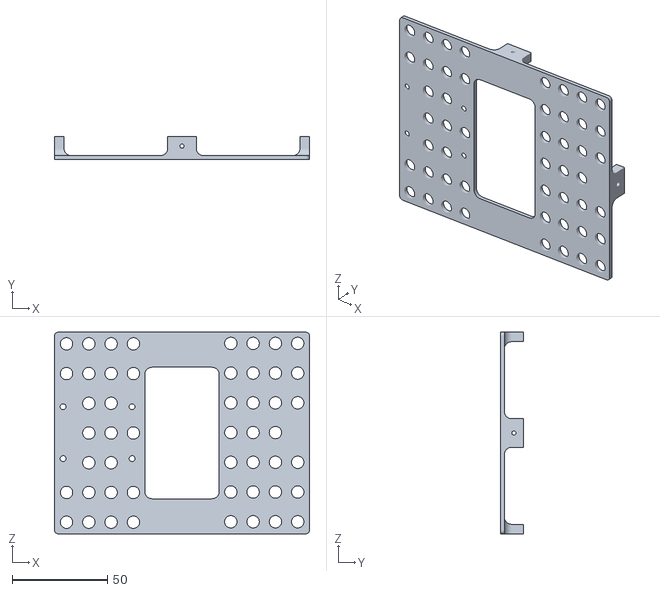
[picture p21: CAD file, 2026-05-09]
CAD_Files/STL/SOLAR_PANEL_bottom_cover_138x110mm.STL
133.8 x 12.0 x 105.8

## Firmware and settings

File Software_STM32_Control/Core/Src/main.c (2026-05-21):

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
/* Includes ------------------------------------------------------------------*/
#include "main.h"

/* USER CODE BEGIN Includes */
#include <stdlib.h>
#include <stdio.h>
/* USER CODE END Includes */

/* USER CODE BEGIN PTD */

/* 1-D Kalman filter state for LDR noise reduction */
typedef struct {
    float x;    /* State estimate */
    float p;    /* Estimate covariance */
    float q;    /* Process noise */
    float r;    /* Measurement noise */
} Kalman1D;

/* PID controller with derivative-on-measurement and filtered derivative */
typedef struct {
    float kp;
    float ki;
    float kd;
    float integral;
    float prev_error;
    float prev_measurement;
    float i_limit;
    float d_filtered;
    float d_alpha;
    float prev_raw_d;
} PID;
/* USER CODE END PTD */

/* USER CODE BEGIN PD */

/* Servo PWM pulse limits (microseconds) */
#define PAN_MIN              500
#define PAN_MAX              2000
#define TILT_MIN             500
#define TILT_MAX             1300

/* Output low-pass filter (1.0 = disabled, smaller = more smoothing) */
#define SMOOTH_ALPHA         0.95f

/* Adaptive deadband bounds (LDR ADC units) */
#define TOL_MIN              50.0f
#define TOL_MAX              80.0f

/* Number of ADC samples averaged per LDR read */
#define LDR_SAMPLES          3

/* Consecutive out-of-band samples required before PID activates */
#define CONFIRM_THRESH       2

/* Slew rate limit: max change in servo target per control loop (us) */
#define MAX_DELTA_PER_LOOP   15.0f

/* Fixed control loop period (ms) for deterministic sampling */
#define LOOP_PERIOD_MS       5
/* USER CODE END PD */

ADC_HandleTypeDef hadc1;
TIM_HandleTypeDef htim1;
UART_HandleTypeDef huart2;

/* USER CODE BEGIN PV */

/* Raw ADC values from the four LDR sensors (Top-Left, Top-Right, Bottom-Left, Bottom-Right) */
uint16_t ldr_TL = 0, ldr_TR = 0, ldr_BL = 0, ldr_BR = 0;

/* Per-sensor Kalman filters: initial state 2048 (mid-range), tuned Q/R for slow light changes */
Kalman1D k_TL = {2048, 1.0f, 2.0f, 200.0f};
Kalman1D k_TR = {2048, 1.0f, 2.0f, 200.0f};
Kalman1D k_BL = {2048, 1.0f, 2.0f, 200.0f};
Kalman1D k_BR = {2048, 1.0f, 2.0f, 200.0f};

/* PID gains tuned for MG996R servo + 10k pull-down LDR bridge at 200 Hz loop rate.
 * Field order: kp, ki, kd, integral, prev_error, prev_measurement, i_limit, d_filtered, d_alpha, prev_raw_d
 */
PID pid_pan  = {0.0045f, 0.002f, 0.0005f, 0, 0, 0, 20.0f, 0, 0.15f, 0};
PID pid_tilt = {0.0045f, 0.002f, 0.0005f, 0, 0, 0, 20.0f, 0, 0.15f, 0};

/* Servo target (PID output) and smoothed position (PWM command) */
float target_pan  = 1250;
float target_tilt = 900;
float pos_pan     = 1250;
float pos_tilt    = 900;

/* PID active flags - controllers idle when error stays within deadband */
uint8_t pan_active  = 0;
uint8_t tilt_active = 0;

/* Counters used to debounce PID activation on transient noise */
uint8_t pan_confirm  = 0;
uint8_t tilt_confirm = 0;
/* USER CODE END PV */

void SystemClock_Config(void);
static void MX_GPIO_Init(void);
static void MX_USART2_UART_Init(void);
static void MX_ADC1_Init(void);
static void MX_TIM1_Init(void);
/* USER CODE BEGIN 0 */

/* Reads a single ADC channel multiple times and returns the average.
 * Software oversampling reduces noise from LDR thermal drift and supply ripple.
 */
uint16_t Read_LDR_Avg(uint32_t Channel) {
    ADC_ChannelConfTypeDef sConfig = {0};
    sConfig.Channel = Channel;
    sConfig.Rank = ADC_REGULAR_RANK_1;
    sConfig.SamplingTime = ADC_SAMPLINGTIME_COMMON_1;
    HAL_ADC_ConfigChannel(&hadc1, &sConfig);

    uint32_t sum = 0;
    for (int i = 0; i < LDR_SAMPLES; i++) {
        HAL_ADC_Start(&hadc1);
        HAL_ADC_PollForConversion(&hadc1, 10);
        sum += HAL_ADC_GetValue(&hadc1);
    }
    HAL_ADC_Stop(&hadc1);

    return (uint16_t)(sum / LDR_SAMPLES);
}

/* Standard 1-D Kalman filter update step.
 * Predicts forward, then corrects with the new measurement.
 */
float Kalman_Update(Kalman1D *k, float measurement) {
    k->p = k->p + k->q;
    float kg = k->p / (k->p + k->r);
    k->x = k->x + kg * (measurement - k->x);
    k->p = (1.0f - kg) * k->p;
    return k->x;
}

/* Adaptive deadband scales with ambient light level.
 * Brighter ambient means more noise on the differential signal,
 * so the deadband widens proportionally.
 */
float Calc_Adaptive_Tol(float ambient) {
    float ratio = ambient / 4096.0f;
    return TOL_MIN + ratio * (TOL_MAX - TOL_MIN);
}

/* PID update with several industrial-grade features:
 *  - Tustin (trapezoidal) integration for accurate discrete-time behavior
 *  - Derivative on measurement (not error) to prevent derivative kick on setpoint changes
 *  - Low-pass filter on derivative to attenuate sensor noise
 *  - Hysteresis-based deadband with confirmation counter (debounced activation)
 *  - Asymmetric enter/exit thresholds prevent limit cycling at the boundary
 *  - Integral clamping for anti-windup
 */
float PID_Update(PID *pid, float setpoint, float measurement, float dt,
                 uint8_t *active, float tol, uint8_t *confirm) {
    float error = setpoint - measurement;
    float thr_enter = tol;
    float thr_exit  = tol * 2.5f;

    if (error > -thr_enter && error < thr_enter) {
        /* Inside deadband */
        *confirm = 0;
        if (*active) {
            /* Already active - require deeper return before deactivating (hysteresis) */
            if (error > -thr_exit && error < thr_exit) {
                pid->integral   = 0.0f;
                pid->prev_error = 0.0f;
                pid->prev_measurement = measurement;
                pid->d_filtered = 0.0f;
                pid->prev_raw_d = 0.0f;
                *active = 0;
            }
        }
        if (!(*active)) {
            /* Track measurement while idle so derivative is sane on next activation */
            pid->prev_measurement = measurement;
            return 0.0f;
        }
    } else {
        /* Outside deadband */
        if (!(*active)) {
            (*confirm)++;
            pid->prev_measurement = measurement;
            if (*confirm < CONFIRM_THRESH) {
                return 0.0f;
            }
            *active = 1;
            pid->prev_error = error;
        }
    }

    /* Trapezoidal integration with clamping anti-windup */
    pid->integral += (error + pid->prev_error) * 0.5f * dt;
    if (pid->integral >  pid->i_limit) pid->integral =  pid->i_limit;
    if (pid->integral < -pid->i_limit) pid->integral = -pid->i_limit;

    /* Derivative on measurement (negated to match error-derivative sign) with bilinear LPF */
    float raw_d = -(measurement - pid->prev_measurement) / dt;
    float k  = pid->d_alpha * 0.5f;
    float c1 = (1.0f - k) / (1.0f + k);
    float c2 =  k         / (1.0f + k);
    pid->d_filtered = c1 * pid->d_filtered + c2 * (raw_d + pid->prev_raw_d);

    pid->prev_error = error;
    pid->prev_measurement = measurement;
    pid->prev_raw_d = raw_d;

    return (pid->kp * error) + (pid->ki * pid->integral) + (pid->kd * pid->d_filtered);
}

/* Slew rate limiter: caps how much the target can move in a single loop iteration.
 * Prevents large PID outputs from commanding mechanically jarring servo movements.
 */
float Apply_Slew(float delta) {
    if (delta >  MAX_DELTA_PER_LOOP) return  MAX_DELTA_PER_LOOP;
    if (delta < -MAX_DELTA_PER_LOOP) return -MAX_DELTA_PER_LOOP;
    return delta;
}

/* USER CODE END 0 */

/**
  * @brief  The application entry point.
  * @retval int
  */
int main(void)
{
  HAL_Init();

  SystemClock_Config();

  MX_GPIO_Init();
  MX_USART2_UART_Init();
  MX_ADC1_Init();
  MX_TIM1_Init();

  /* USER CODE BEGIN 2 */
  HAL_TIM_PWM_Start(&htim1, TIM_CHANNEL_1);
  HAL_TIM_PWM_Start(&htim1, TIM_CHANNEL_3);

  /* Soft start: smoothly ramp servos from minimum to home position over 1 second.
   * Prevents inrush current spikes and mechanical shock on power-up.
   * Blocking HAL_Delay is acceptable here since this runs only once at boot.
   */
  for (int i = 1; i <= 50; i++) {
        uint16_t p = PAN_MIN + (uint16_t)((1250.0f - PAN_MIN) * i / 50.0f);
        uint16_t t = TILT_MIN + (uint16_t)((900.0f - TILT_MIN) * i / 50.0f);

        __HAL_TIM_SET_COMPARE(&htim1, TIM_CHANNEL_1, p);
        __HAL_TIM_SET_COMPARE(&htim1, TIM_CHANNEL_3, t);
        HAL_Delay(20);
    }

  uint32_t prev_time = HAL_GetTick();
  uint32_t next_tick = HAL_GetTick() + LOOP_PERIOD_MS;
  /* USER CODE END 2 */

  /* Infinite loop */
  /* USER CODE BEGIN WHILE */
  while (1)
  {
    /* USER CODE END WHILE */

    /* USER CODE BEGIN 3 */

    /* Non-blocking timer: run control loop every LOOP_PERIOD_MS milliseconds.
     * Signed cast handles 32-bit tick counter overflow correctly (~49 day rollover).
     */
    if ((int32_t)(HAL_GetTick() - next_tick) >= 0) {
        next_tick += LOOP_PERIOD_MS;

        /* If execution fell far behind (e.g. due to a debug breakpoint),
         * skip the catch-up burst and resync to the current time.
         */
        if ((int32_t)(HAL_GetTick() - next_tick) > 100) {
            next_tick = HAL_GetTick() + LOOP_PERIOD_MS;
        }

        /* Measure actual loop period for PID time-step.
         * Even with the fixed schedule, using measured dt keeps the math correct
         * if the schedule slips.
         */
        uint32_t current_time = HAL_GetTick();
        float dt = (current_time - prev_time) / 1000.0f;
        if (dt < 0.001f) dt = 0.001f;
        prev_time = current_time;

        /* Read the four LDRs. Channel mapping is set by the PCB layout. */
        ldr_TL = Read_LDR_Avg(ADC_CHANNEL_4);
        ldr_TR = Read_LDR_Avg(ADC_CHANNEL_1);
        ldr_BL = Read_LDR_Avg(ADC_CHANNEL_5);
        ldr_BR = Read_LDR_Avg(ADC_CHANNEL_0);

        /* Kalman filter each sensor independently for noise reduction. */
        float f_TL = Kalman_Update(&k_TL, ldr_TL);
        float f_TR = Kalman_Update(&k_TR, ldr_TR);
        float f_BL = Kalman_Update(&k_BL, ldr_BL);
        float f_BR = Kalman_Update(&k_BR, ldr_BR);

        /* Compute the four edge averages used for differential error signals. */
        float avg_top    = (f_TL + f_TR) / 2.0f;
        float avg_bottom = (f_BL + f_BR) / 2.0f;
        float avg_left   = (f_TL + f_BL) / 2.0f;
        float avg_right  = (f_TR + f_BR) / 2.0f;

        /* Ambient light estimate drives the adaptive deadband. */
        float ambient      = (f_TL + f_TR + f_BL + f_BR) / 4.0f;
        float adaptive_tol = Calc_Adaptive_Tol(ambient);

        /* Setpoint is zero: we want left=right and top=bottom (perfectly aimed at the sun). */
        float setpoint = 0.0f;

        /* Differential measurements: positive pan means right side is brighter,
         * positive tilt means bottom is brighter.
         */
        float meas_pan  = avg_right - avg_left;
        float meas_tilt = avg_bottom - avg_top;

        /* Run both PID controllers. */
        float out_pan  = PID_Update(&pid_pan,  setpoint, meas_pan,  dt, &pan_active,  adaptive_tol, &pan_confirm);
        float out_tilt = PID_Update(&pid_tilt, setpoint, meas_tilt, dt, &tilt_active, adaptive_tol, &tilt_confirm);

        /* Apply slew limit and update servo targets.
         * Sign is negated: positive error (light unbalanced right) needs servo to move toward light.
         */
        float dpan  = Apply_Slew(-out_pan);
        float dtilt = Apply_Slew(-out_tilt);
        target_pan  += dpan;
        target_tilt += dtilt;

        /* Conditional anti-windup: when the target saturates against a limit,
         * clear any integral pushing further into the saturation.
         */
        if (target_pan > PAN_MAX) {
            target_pan = PAN_MAX;
            if (pid_pan.integral < 0) pid_pan.integral = 0;
        } else if (target_pan < PAN_MIN) {
            target_pan = PAN_MIN;
            if (pid_pan.integral > 0) pid_pan.integral = 0;
        }

        if (target_tilt > TILT_MAX) {
            target_tilt = TILT_MAX;
            if (pid_tilt.integral < 0) pid_tilt.integral = 0;
        } else if (target_tilt < TILT_MIN) {
            target_tilt = TILT_MIN;
            if (pid_tilt.integral > 0) pid_tilt.integral = 0;
        }

        /* Optional low-pass on the commanded position (currently near-disabled at 0.95). */
        pos_pan  = pos_pan  + SMOOTH_ALPHA * (target_pan  - pos_pan);
        pos_tilt = pos_tilt + SMOOTH_ALPHA * (target_tilt - pos_tilt);

        /* Send PWM command to the servos. */
        __HAL_TIM_SET_COMPARE(&htim1, TIM_CHANNEL_1, (uint16_t)(pos_pan + 0.5f));
        __HAL_TIM_SET_COMPARE(&htim1, TIM_CHANNEL_3, (uint16_t)(pos_tilt + 0.5f));
    }

    /* CPU is free between control loop iterations - background tasks can run here. */
  }
  /* USER CODE END 3 */
}

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
void Error_Handler(void)
{
  /* USER CODE BEGIN Error_Handler_Debug */
  __disable_irq();
  while (1)
  {
  }
  /* USER CODE END Error_Handler_Debug */
}

#ifdef  USE_FULL_ASSERT
void assert_failed(uint8_t *file, uint32_t line)
{
}
#endif /* USE_FULL_ASSERT */

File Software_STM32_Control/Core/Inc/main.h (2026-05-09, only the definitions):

#define T_NRST_Pin GPIO_PIN_2
#define T_NRST_GPIO_Port GPIOF
#define LDR_BR_Pin GPIO_PIN_0
#define LDR_BR_GPIO_Port GPIOA
#define LDR_TR_Pin GPIO_PIN_1
#define LDR_TR_GPIO_Port GPIOA
#define T_VCP_TX_Pin GPIO_PIN_2
#define T_VCP_TX_GPIO_Port GPIOA
#define T_VCP_RX_Pin GPIO_PIN_3
#define T_VCP_RX_GPIO_Port GPIOA
#define LDR_TL_Pin GPIO_PIN_4
#define LDR_TL_GPIO_Port GPIOA
#define LDR_BL_Pin GPIO_PIN_5
#define LDR_BL_GPIO_Port GPIOA
#define SERVO_PAN_Pin GPIO_PIN_8
#define SERVO_PAN_GPIO_Port GPIOA
#define LD3_Pin GPIO_PIN_6
#define LD3_GPIO_Port GPIOC
#define SERVO_TILT_Pin GPIO_PIN_10
#define SERVO_TILT_GPIO_Port GPIOA
#define T_JTMS_Pin GPIO_PIN_13
#define T_JTMS_GPIO_Port GPIOA
#define T_JTCK_Pin GPIO_PIN_14
#define T_JTCK_GPIO_Port GPIOA

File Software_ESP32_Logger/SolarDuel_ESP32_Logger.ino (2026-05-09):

#include <WiFi.h>
#include <WebServer.h>
#include <Wire.h>
#include <INA226_WE.h>

const char* ssid     = "WIFI-NAME";
const char* password = "WIFI-PASS";

WebServer server(80);

#define I2C_ADDRESS  0x40
#define PANEL_MAX_W  0.9f
#define LOG_SIZE     3600  // 1 entry/sec = 1 hour max
#define GRAPH_SIZE   60    // Last 60 seconds shown on graph

INA226_WE ina226 = INA226_WE(I2C_ADDRESS);

float totalEnergy_Wh = 0.0;
unsigned long lastTime = 0;

struct LogEntry {
  unsigned long t_sec;
  float voltage;
  float current;
  float power;
  float energy;
};

LogEntry logBuf[LOG_SIZE];
int  logCount  = 0;
bool recording = false;

// Circular buffer for graph data (last 60 power readings in mW)
float graphBuf[GRAPH_SIZE];
int   graphHead  = 0;
int   graphCount = 0;

// ─────────────────────────────────────────────────────────────
const char index_html[] PROGMEM = R"rawliteral(
<!DOCTYPE HTML><html>
<head>
  <meta charset="UTF-8">
  <meta name="viewport" content="width=device-width, initial-scale=1">
  <title>SolarDuel Dashboard</title>
  <style>
    body { font-family: 'Segoe UI', Tahoma, Geneva, Verdana, sans-serif; background-color: #121212; color: #fff; text-align: center; margin: 0; padding: 20px; }
    h2 { color: #f39c12; margin-bottom: 30px; letter-spacing: 1px; }
    .grid-container { display: grid; grid-template-columns: 1fr 1fr; gap: 15px; max-width: 600px; margin: 0 auto; }
    .card { background-color: #1e1e1e; padding: 20px; border-radius: 10px; box-shadow: 0 4px 8px rgba(0,0,0,0.4); border: 1px solid #333; }
    .card.full { grid-column: span 2; }
    .val { font-size: 28px; font-weight: bold; color: #4CAF50; margin-top: 10px; }
    .val.blue   { color: #38bdf8; }
    .val.yellow { color: #facc15; }
    .label { font-size: 14px; color: #aaaaaa; text-transform: uppercase; letter-spacing: 1px; }

    /* Graph */
    .graph-card { background-color: #1e1e1e; border-radius: 10px; border: 1px solid #333; padding: 16px 16px 8px; max-width: 600px; margin: 15px auto 0; }
    .graph-title { font-size: 13px; color: #aaaaaa; text-transform: uppercase; letter-spacing: 1px; margin-bottom: 8px; }
    canvas { width: 100% !important; height: 140px !important; display: block; }

    /* Buttons */
    .btn-row { display: flex; justify-content: center; gap: 12px; flex-wrap: wrap; margin-top: 20px; }
    .btn {
      padding: 13px 28px; border-radius: 8px;
      font-size: 14px; font-weight: bold;
      border: none; cursor: pointer;
      letter-spacing: 0.5px; transition: background 0.2s; color: #fff;
    }
    .btn-start { background: #16a34a; }
    .btn-start:hover { background: #15803d; }
    .btn-stop  { background: #dc2626; }
    .btn-stop:hover  { background: #b91c1c; }
    .btn-reset { background: #475569; }
    .btn-reset:hover { background: #334155; }

    #rec-status { margin-top: 12px; font-size: 13px; color: #555; }
    #rec-dot { display:inline-block; width:9px; height:9px; border-radius:50%; background:#555; margin-right:5px; vertical-align:middle; }
    #rec-dot.active { background:#ef4444; animation: blink 1s infinite; }
    @keyframes blink { 0%,100%{opacity:1} 50%{opacity:0.2} }
    .footer { margin-top: 16px; font-size: 12px; color: #555; }
    @media (max-width: 400px) { .grid-container { grid-template-columns: 1fr; } .card.full { grid-column: span 1; } }
  </style>
</head>
<body>
  <h2>🌟 SolarDuel Pro Dashboard</h2>

  <div class="grid-container">
    <div class="card">
      <div class="label">Panel Voltage</div>
      <div class="val"><span id="voltage">--</span> V</div>
    </div>
    <div class="card">
      <div class="label">Current Draw</div>
      <div class="val"><span id="current">--</span> mA</div>
    </div>
    <div class="card">
      <div class="label">Instant Power</div>
      <div class="val yellow"><span id="power">--</span> mW</div>
    </div>
    <div class="card">
      <div class="label">Total Energy</div>
      <div class="val blue"><span id="energy">--</span> Wh</div>
    </div>
    <div class="card full">
      <div class="label">Panel Efficiency</div>
      <div class="val"><span id="efficiency">--</span> %</div>
    </div>
  </div>

  <!-- Power Graph -->
  <div class="graph-card">
    <div class="graph-title">⚡ Power — Last 60 Seconds (mW)</div>
    <canvas id="graph"></canvas>
  </div>

  <!-- Buttons -->
  <div class="btn-row">
    <button id="recBtn" class="btn btn-start" onclick="toggleRecording()">⏺ Start Recording</button>
    <button class="btn btn-reset" onclick="resetAll()">Reset All</button>
  </div>

  <div id="rec-status">
    <span id="rec-dot"></span>
    <span id="rec-text">Not recording</span>
  </div>

  <div class="footer" id="status">Connected. Updating every second.</div>

  <script>
    let isRecording = false;

    // ── Graph Setup ───────────────────────────────────────────
    const canvas  = document.getElementById('graph');
    const ctx     = canvas.getContext('2d');
    let graphData = [];

    function drawGraph(data) {
      const W = canvas.offsetWidth;
      const H = canvas.offsetHeight;
      canvas.width  = W;
      canvas.height = H;

      const pad = { top: 10, bottom: 24, left: 40, right: 10 };
      const w = W - pad.left - pad.right;
      const h = H - pad.top  - pad.bottom;

      ctx.clearRect(0, 0, W, H);

      const max = Math.max(...data, 0.01);

      // Grid lines
      ctx.strokeStyle = '#2d3748';
      ctx.lineWidth   = 1;
      for (let i = 0; i <= 4; i++) {
        const y = pad.top + (h / 4) * i;
        ctx.beginPath(); ctx.moveTo(pad.left, y); ctx.lineTo(pad.left + w, y); ctx.stroke();
        ctx.fillStyle = '#4a5568';
        ctx.font = '10px Segoe UI';
        ctx.textAlign = 'right';
        ctx.fillText((max * (1 - i / 4)).toFixed(1), pad.left - 4, y + 4);
      }

      if (data.length < 2) return;

      // Fill area
      const grad = ctx.createLinearGradient(0, pad.top, 0, pad.top + h);
      grad.addColorStop(0,   'rgba(250, 204, 21, 0.4)');
      grad.addColorStop(1,   'rgba(250, 204, 21, 0.02)');
      ctx.fillStyle = grad;
      ctx.beginPath();
      data.forEach((v, i) => {
        const x = pad.left + (i / (data.length - 1)) * w;
        const y = pad.top  + h - (v / max) * h;
        i === 0 ? ctx.moveTo(x, y) : ctx.lineTo(x, y);
      });
      ctx.lineTo(pad.left + w, pad.top + h);
      ctx.lineTo(pad.left,     pad.top + h);
      ctx.closePath();
      ctx.fill();

      // Line
      ctx.strokeStyle = '#facc15';
      ctx.lineWidth   = 2;
      ctx.lineJoin    = 'round';
      ctx.beginPath();
      data.forEach((v, i) => {
        const x = pad.left + (i / (data.length - 1)) * w;
        const y = pad.top  + h - (v / max) * h;
        i === 0 ? ctx.moveTo(x, y) : ctx.lineTo(x, y);
      });
      ctx.stroke();
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

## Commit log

2026-05-09 hardware: add 3D printable STL files for pan-tilt system
    Includes base blocks, vertical brackets, and solar panel covers optimized for 3D printing.
    [MG995_TILT_PAN_base_block.STL, MG995_TILT_PAN_base_lid.STL, MG995_TILT_PAN_corner.STL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]
2026-05-09 feat: add STM32 control firmware for dual-axis solar tracking
    Initializes the core control project for the STM32G031K8 microcontroller using STM32CubeIDE (.ioc). Includes peripheral configurations, HAL drivers, and the main control loop logic to drive the pan-t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
2026-05-09 feat: add ESP32-S3 data logger firmware for power monitoring
    Adds the main Arduino (.ino) sketch for the ESP32-S3 data acquisition module. Handles real-time reading of voltage and current sensors to log power generation metrics, providing the raw data required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
2026-05-09 docs: add hardware circuit schematic for dual-axis tracker
    Includes the complete electrical wiring diagram (hardware_schematic.pdf) detailing the connections between the STM32G031K8, ESP32-S3, MG995 servos, and power sensors.
2026-05-09 docs: add comprehensive project report and physical prototype visuals
    Uploads the final project report, the dashboard interface, and a high-quality system photo of the assembled mechatronic prototype.
2026-05-09 docs: add demonstration videos of active tracking and live telemetry
    ploads video recordings showcasing the physical mechatronic pan-tilt system in action and the real-time data logging dashboard. Demonstrates the successful integration of the STM32 control logic with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

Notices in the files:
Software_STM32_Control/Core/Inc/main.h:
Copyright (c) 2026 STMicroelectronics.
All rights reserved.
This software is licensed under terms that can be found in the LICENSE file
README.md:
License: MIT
